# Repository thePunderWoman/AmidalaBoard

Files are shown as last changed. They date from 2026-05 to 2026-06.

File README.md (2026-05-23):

# AmidalaBoard (AmidalaShield)

A custom KiCad PCB shield designed specifically for the [Amidala Firmware](https://github.com/thePunderWoman/AmidalaFirmware) — a control system for astromech and similar droid builds. This board provides all the I/O the firmware needs in a single, purpose-built package.

**Designed by [thePunderWoman](https://github.com/thePunderWoman)**

---

## Overview

The AmidalaShield is a carrier/breakout board for the **ESP32-S3 N16R8 DevKit**. It breaks out and conditions the ESP32-S3's peripherals for the specific needs of the Amidala Firmware: wireless XBee communication, multi-channel servo control, RC receiver input, SD card storage, and expansion headers for additional peripherals.

---

## Requirements

- **Microcontroller:** ESP32-S3 N16R8 DevKit (16 MB flash, 8 MB PSRAM)
- **Wireless modules:** XBee3 modules (x2 recommended — one for drive controller, one for dome controller)

---

## Hardware Features

### Wireless Communication
- **2× XBee3 module sockets** for dual-controller operation (drive + dome)

### Servo Control
- **8× PWM servo outputs** — 3-pin headers (signal, power, ground)

### Serial Ports
- **2× hardware serial ports** — UART0 (shared with USB/programming) and UART1
- **1× software serial port** — for additional peripherals

### I/O
- **6× digital I/O pins**
- **2× analog input pins**
- **1× Aux I2C header** — for external I2C devices

### RC Control
- **PPM input (ppmin)** — for analog RC receiver
- **RC select (rcsel)** — RC source selection
- **sel2** — secondary selection/mode pin

### Storage
- **Built-in microSD card reader** — used for `config.txt` at startup (matches Amidala Firmware config system)

### Expansion
- **Dedicated SPI header** — for external SPI peripherals

---

## Repository Contents

| File/Folder | Description |
|---|---|
| `AmidalaShield.kicad_sch` | Top-level schematic |
| `comms.kicad_sch` | XBee communications sub-sheet |
| `io.kicad_sch` | Digital/analog I/O sub-sheet |
| `power.kicad_sch` | Power distribution sub-sheet |
| `rc_control.kicad_sch` | RC input sub-sheet |
| `servos.kicad_sch` | Servo output sub-sheet |
| `spi.kicad_sch` | SPI header sub-sheet |
| `gerbers/` | Production-ready Gerber files |
| `libraries/` | Project-specific KiCad symbol/footprint libraries |
| `images/` | Board renders and screenshots |

---

## Getting Started

1. Clone this repo and open `AmidalaShield.kicad_pro` in KiCad 8+.
2. Review the schematics for pin assignments before assembling.
3. Use the Gerber files in `gerbers/` to order PCBs from your preferred fab.
4. Flash your ESP32-S3 with the [Amidala Firmware](https://github.com/thePunderWoman/AmidalaFirmware).
5. Place a `config.txt` on the microSD card — see the firmware repo for a full annotated example.

---

## GPIO Table

> **V1.1** — Updated GPIO assignments for ESP32-S3 WROOM-1 N8R2/N16R2 (Quad flash/PSRAM).
> Avoid GPIO35–37 on R8 (Octal) variants. GPIO48 reserved for onboard RGB LED.

| Function | GPIO | DevKit Side | Notes |
|---|---|---|---|
| **SPI MOSI** | GPIO11 | Left | Native FSPI, shared bus |
| **SPI MISO** | GPIO13 | Left | Native FSPI, shared bus |
| **SPI SCK** | GPIO12 | Left | Native FSPI, shared bus |
| **SD Card CS** | GPIO10 | Left | |
| **XBee CS** | GPIO7 | Left | |
| **SPI Spare CS** | GPIO14 | Left | Exposed header |
| **XBee ATTN** | GPIO16 | Left | |
| **XBee SLEEP** | GPIO15 | Left | |
| **I2C SDA** | GPIO8 | Left | Native I2C default |
| **I2C SCL** | GPIO9 | Left | Native I2C default |
| **UART0 TX** | GPIO43 | Right | Shared w/ USB — do not use simultaneously |
| **UART0 RX** | GPIO44 | Right | Shared w/ USB — do not use simultaneously |
| **UART1 TX** | GPIO17 | Right | Primary droid brain serial |
| **UART1 RX** | GPIO18 | Right | |
| **SW-UART TX** | GPIO21 | Right | |
| **SW-UART RX** | GPIO38 | Right | |
| **PPMIN** | GPIO47 | Right | |
| **Analog 1** | GPIO1 | Right | ADC1_0, WiFi-safe |
| **Analog 2** | GPIO2 | Right | ADC1_1, WiFi-safe |
| **Servo 1** | GPIO3 | Left | Strapping pin (JTAG source), safe after boot |
| **Servo 2** | GPIO4 | Left | |
| **Servo 3** | GPIO5 | Left | |
| **Servo 4** | GPIO6 | Left | |
| **Digital 1** | GPIO39 | Right | Goes HIGH after reset (not LOW like most GPIOs) |
| **Digital 2** | GPIO40 | Right | |
| **Digital 3** | GPIO41 | Right | |
| **Digital 4** | GPIO42 | Right | Transitions low on reset slightly slower |
| **RGB LED** | GPIO48 | Right | Reserved — onboard DevKit RGB LED |
| **NC** | GPIO8 | Left | Reserved |

### Pins Intentionally Avoided

| GPIO | Reason |
|---|---|
| GPIO0 | Strapping pin — boot mode |
| GPIO3 | Strapping pin — JTAG source (used for Servo 1, safe after boot) |
| GPIO19/20 | USB D-/D+ |
| GPIO26–32 | Internal SPI flash/PSRAM — never use |
| GPIO35–37 | Internal on Octal (R8) variants — safe on R2 only |
| GPIO45 | Strapping pin — VDD_SPI voltage |
| GPIO46 | Strapping pin |

---

## License

This hardware design is licensed under the [Creative Commons Attribution-NonCommercial-ShareAlike 4.0 International License](LICENSE.md) (CC BY-NC-SA 4.0).

You are free to share and adapt this design for non-commercial purposes, as long as you give appropriate credit and distribute any adaptations under the same license.

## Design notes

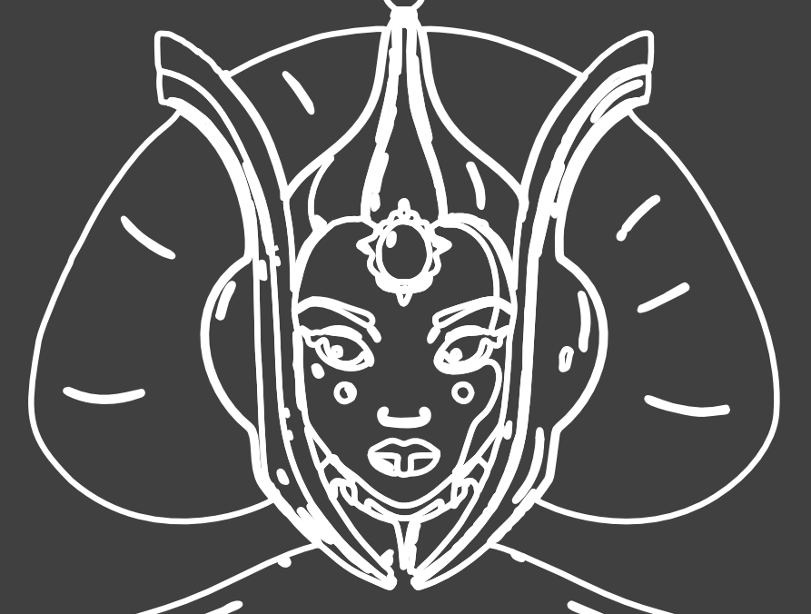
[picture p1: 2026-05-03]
images/amidala-screen.png

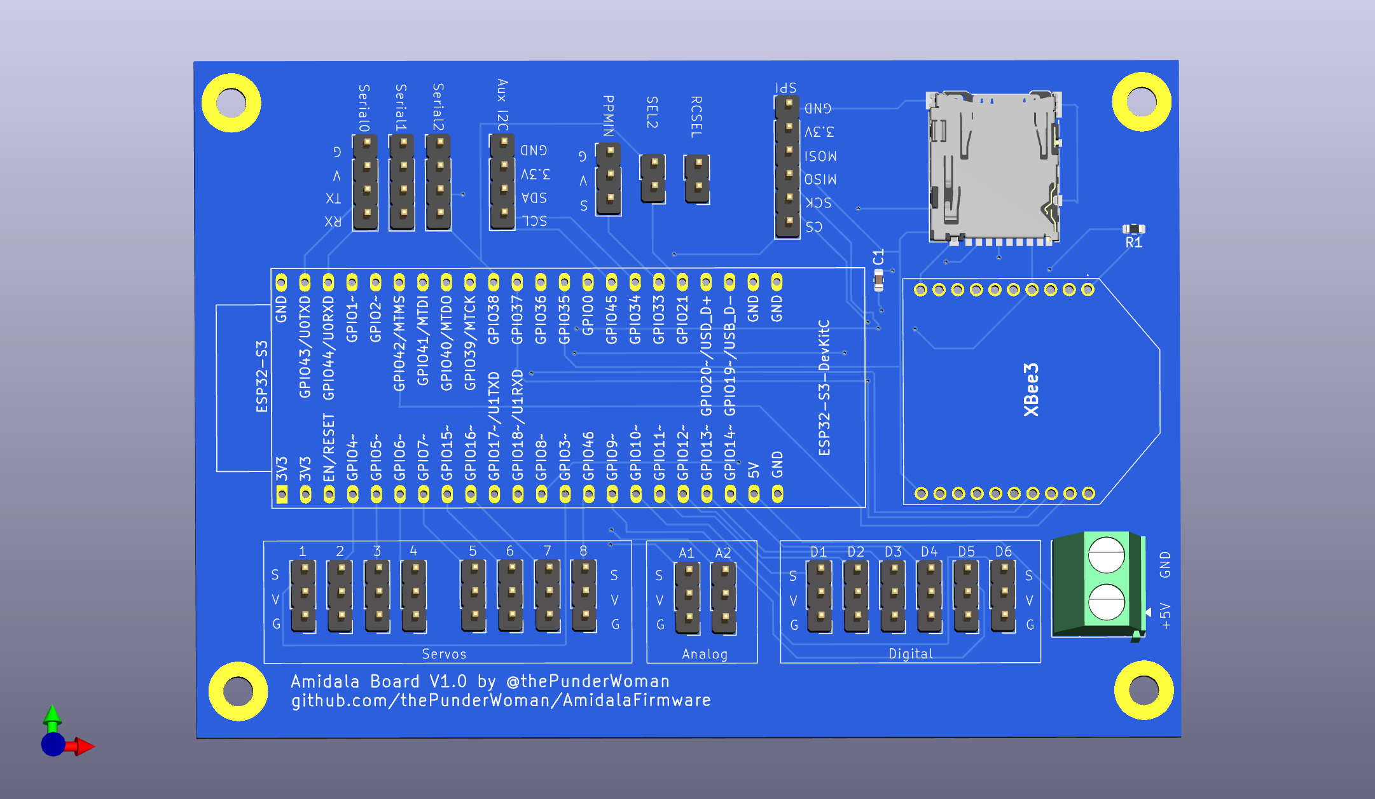
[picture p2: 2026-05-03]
V1-PCB.png

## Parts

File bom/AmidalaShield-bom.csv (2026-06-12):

Id | Designator | Footprint | Quantity | Designation | Supplier and ref
1 | C9 | CP_EIA-3216-18_Kemet-A | 1 | 100µF
2 | C4,C7 | C_0805_2012Metric | 2 | 10u
3 | C3,C2,C1 | C_0603_1608Metric | 3 | 100n
4 | R1,R5,R3,R2 | R_0603_1608Metric | 4 | 10k
5 | C6 | C_0603_1608Metric | 1 | 8.2p
6 | C5 | C_0603_1608Metric | 1 | 1u
7 | J3 | microSD_HC_Hirose_DM3AT-SF-PEJM5 | 1 | Micro_SD_Card

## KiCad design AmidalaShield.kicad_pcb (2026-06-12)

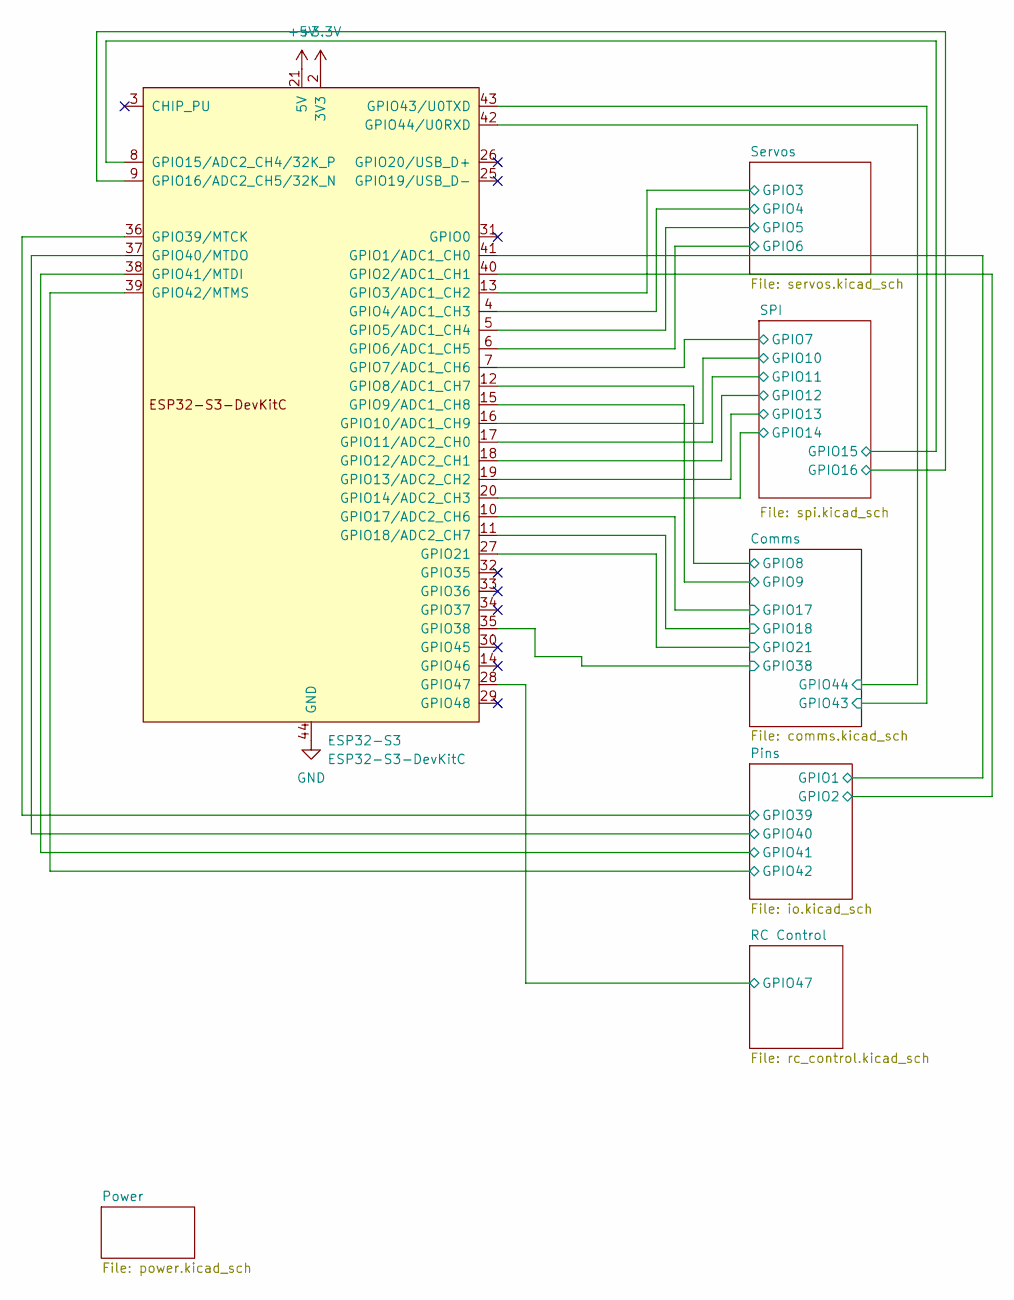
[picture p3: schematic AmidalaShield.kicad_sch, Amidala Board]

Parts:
ESP32-S3: ESP32-S3-DevKitC; ESP32-S2-DevKitC-1

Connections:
+3.3V: ESP32-S3.1 (3V3), ESP32-S3.2 (3V3); also elsewhere on the board
+5V: ESP32-S3.21 (5V); also elsewhere on the board
/Comms/GPIO8: ESP32-S3.12 (GPIO8/ADC1_CH7); also elsewhere on the board
/Comms/GPIO9: ESP32-S3.15 (GPIO9/ADC1_CH8); also elsewhere on the board
/Comms/GPIO17: ESP32-S3.10 (GPIO17/ADC2_CH6); also elsewhere on the board
/Comms/GPIO18: ESP32-S3.11 (GPIO18/ADC2_CH7); also elsewhere on the board
/Comms/GPIO21: ESP32-S3.27 (GPIO21); also elsewhere on the board
/Comms/GPIO38: ESP32-S3.35 (GPIO38); also elsewhere on the board
/Comms/GPIO43: ESP32-S3.43 (GPIO43/U0TXD); also elsewhere on the board
/Comms/GPIO44: ESP32-S3.42 (GPIO44/U0RXD); also elsewhere on the board
/Pins/GPIO1: ESP32-S3.41 (GPIO1/ADC1_CH0); also elsewhere on the board
/Pins/GPIO2: ESP32-S3.40 (GPIO2/ADC1_CH1); also elsewhere on the board
/Pins/GPIO39: ESP32-S3.36 (GPIO39/MTCK); also elsewhere on the board
/Pins/GPIO40: ESP32-S3.37 (GPIO40/MTDO); also elsewhere on the board
/Pins/GPIO41: ESP32-S3.38 (GPIO41/MTDI); also elsewhere on the board
/Pins/GPIO42: ESP32-S3.39 (GPIO42/MTMS); also elsewhere on the board
/RC Control/GPIO47: ESP32-S3.28 (GPIO47); also elsewhere on the board
/SPI/GPIO7: ESP32-S3.7 (GPIO7/ADC1_CH6); also elsewhere on the board
/SPI/GPIO10: ESP32-S3.16 (GPIO10/ADC1_CH9); also elsewhere on the board
/SPI/GPIO11: ESP32-S3.17 (GPIO11/ADC2_CH0); also elsewhere on the board
/SPI/GPIO12: ESP32-S3.18 (GPIO12/ADC2_CH1); also elsewhere on the board
/SPI/GPIO13: ESP32-S3.19 (GPIO13/ADC2_CH2); also elsewhere on the board
/SPI/GPIO14: ESP32-S3.20 (GPIO14/ADC2_CH3); also elsewhere on the board
/SPI/GPIO15: ESP32-S3.8 (GPIO15/ADC2_CH4/32K_P); also elsewhere on the board
/SPI/GPIO16: ESP32-S3.9 (GPIO16/ADC2_CH5/32K_N); also elsewhere on the board
/Servos/GPIO3: ESP32-S3.13 (GPIO3/ADC1_CH2); also elsewhere on the board
/Servos/GPIO4: ESP32-S3.4 (GPIO4/ADC1_CH3); also elsewhere on the board
/Servos/GPIO5: ESP32-S3.5 (GPIO5/ADC1_CH4); also elsewhere on the board
/Servos/GPIO6: ESP32-S3.6 (GPIO6/ADC1_CH5); also elsewhere on the board
GND: ESP32-S3.22 (GND), ESP32-S3.23 (GND), ESP32-S3.24 (GND), ESP32-S3.44 (GND); also elsewhere on the board

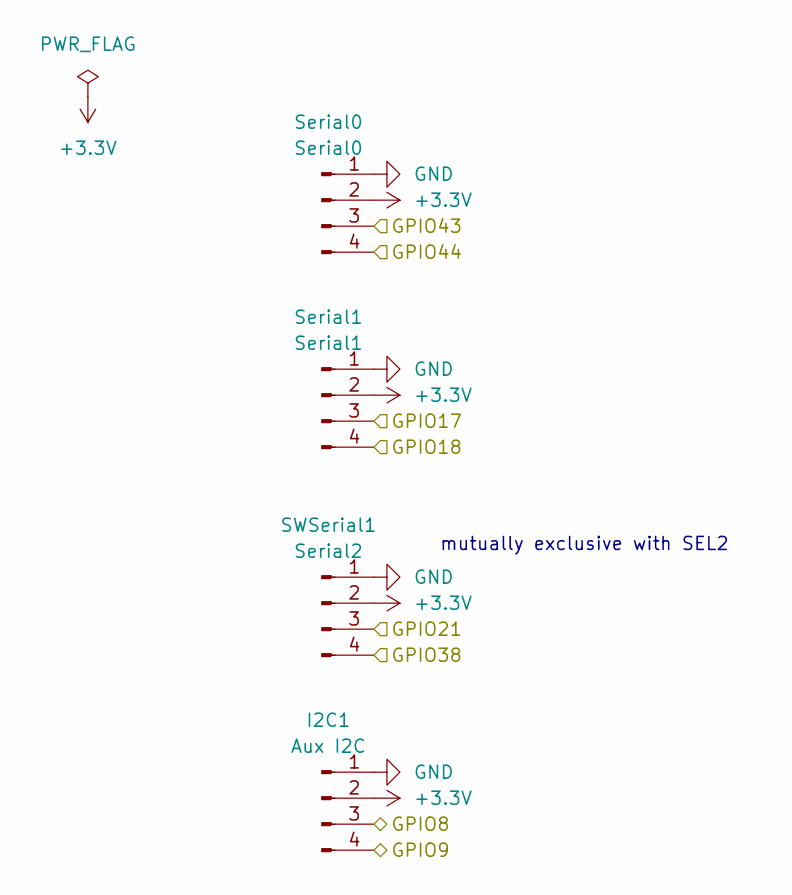
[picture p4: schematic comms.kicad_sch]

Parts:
I2C1: Aux I2C; PinHeader_1x04_P2.54mm_Vertical
SWSerial1: Serial2; PinHeader_1x04_P2.54mm_Vertical
Serial0: Serial0; PinHeader_1x04_P2.54mm_Vertical
Serial1: Serial1; PinHeader_1x04_P2.54mm_Vertical

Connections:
+3.3V: I2C1.2, SWSerial1.2, Serial0.2, Serial1.2; also elsewhere on the board
/Comms/GPIO8: I2C1.3; also elsewhere on the board
/Comms/GPIO9: I2C1.4; also elsewhere on the board
/Comms/GPIO17: Serial1.3; also elsewhere on the board
/Comms/GPIO18: Serial1.4; also elsewhere on the board
/Comms/GPIO21: SWSerial1.3; also elsewhere on the board
/Comms/GPIO38: SWSerial1.4; also elsewhere on the board
/Comms/GPIO43: Serial0.3; also elsewhere on the board
/Comms/GPIO44: Serial0.4; also elsewhere on the board
GND: I2C1.1, SWSerial1.1, Serial0.1, Serial1.1; also elsewhere on the board

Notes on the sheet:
mutually exclusive with SEL2

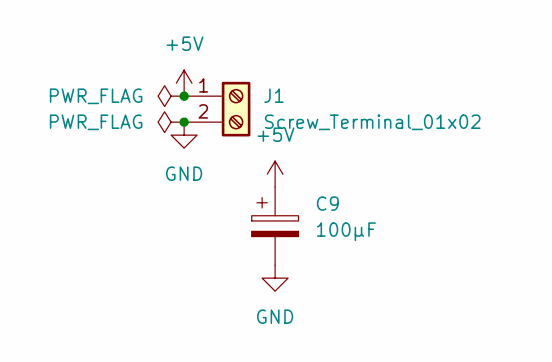
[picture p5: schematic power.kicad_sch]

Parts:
C9: 100µF; CP_EIA-3216-18_Kemet-A
J1: Screw_Terminal_01x02; TerminalBlock_Phoenix_MKDS-1,5-2-5.08_1x02_P5.08mm_Horizont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

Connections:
+5V: C9.1, J1.1; also elsewhere on the board
GND: C9.2, J1.2; also elsewhere on the board

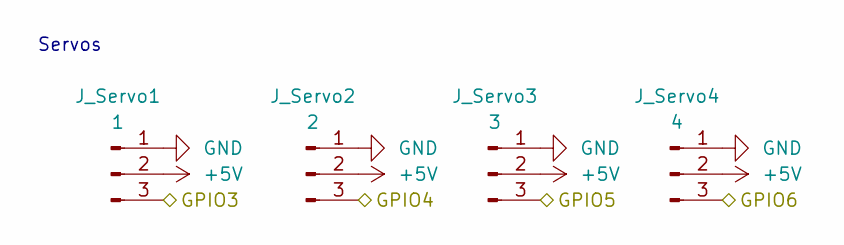
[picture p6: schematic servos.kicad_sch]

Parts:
J_Servo1: 1; PinHeader_1x03_P2.54mm_Vertical
J_Servo2: 2; PinHeader_1x03_P2.54mm_Vertical
J_Servo3: 3; PinHeader_1x03_P2.54mm_Vertical
J_Servo4: 4; PinHeader_1x03_P2.54mm_Vertical

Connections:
+5V: J_Servo1.2, J_Servo2.2, J_Servo3.2, J_Servo4.2; also elsewhere on the board
/Servos/GPIO3: J_Servo1.3; also elsewhere on the board
/Servos/GPIO4: J_Servo2.3; also elsewhere on the board
/Servos/GPIO5: J_Servo3.3; also elsewhere on the board
/Servos/GPIO6: J_Servo4.3; also elsewhere on the board
GND: J_Servo1.1, J_Servo2.1, J_Servo3.1, J_Servo4.1; also elsewhere on the board

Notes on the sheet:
Servos

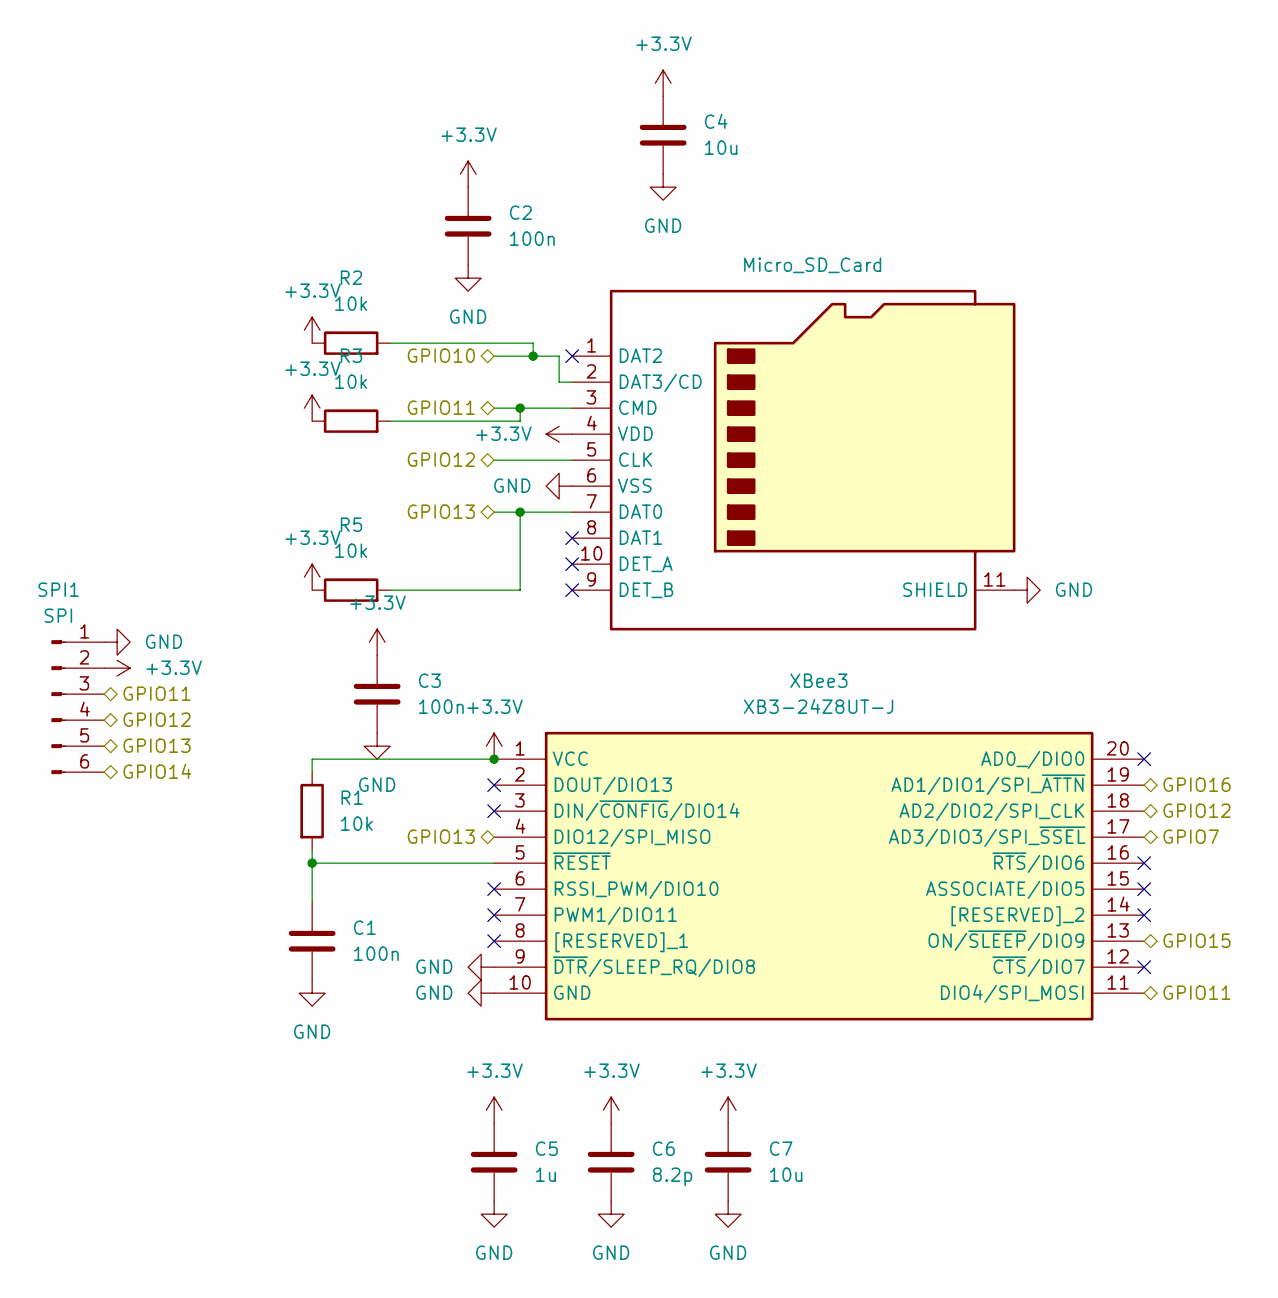
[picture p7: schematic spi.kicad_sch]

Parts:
C1, C2, C3: 100n; C_0603_1608Metric
C4, C7: 10u; C_0805_2012Metric
C5: 1u; C_0603_1608Metric
C6: 8.2p; C_0603_1608Metric
J3: Micro_SD_Card; microSD_HC_Hirose_DM3AT-SF-PEJM5
R1, R2, R3, R5: 10k; R_0603_1608Metric
SPI1: SPI; PinHeader_1x06_P2.54mm_Vertical
XBee3: XB3-24Z8UT-J; XB324Z8UTJ; Mouser Part Number 888-XB3-24Z8UT-J

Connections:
+3.3V: C2.1, C3.1, C4.1, C5.1, C6.1, C7.1, J3.4 (VDD), R1.1, R2.1, R3.1, R5.1, SPI1.2, XBee3.1 (VCC); also elsewhere on the board
/SPI/GPIO7: XBee3.17 (AD3/DIO3/SPI_~SSEL); also elsewhere on the board
/SPI/GPIO10: J3.2 (DAT3/CD), R2.2; also elsewhere on the board
/SPI/GPIO11: J3.3 (CMD), R3.2, SPI1.3, XBee3.11 (DIO4/SPI_MOSI); also elsewhere on the board
/SPI/GPIO12: J3.5 (CLK), SPI1.4, XBee3.18 (AD2/DIO2/SPI_CLK); also elsewhere on the board
/SPI/GPIO13: J3.7 (DAT0), R5.2, SPI1.5, XBee3.4 (DIO12/SPI_MISO); also elsewhere on the board
/SPI/GPIO14: SPI1.6; also elsewhere on the board
/SPI/GPIO15: XBee3.13 (ON/~SLEEP/DIO9); also elsewhere on the board
/SPI/GPIO16: XBee3.19 (AD1/DIO1/SPI_~ATTN); also elsewhere on the board
GND: C1.2, C2.2, C3.2, C4.2, C5.2, C6.2, C7.2, J3.6 (VSS), J3.11 (SHIELD), SPI1.1, XBee3.9 (~DTR/SLEEP_RQ/DIO8), XBee3.10 (GND); also elsewhere on the board
unnamed: C1.1, R1.2, XBee3.5 (~RESET)

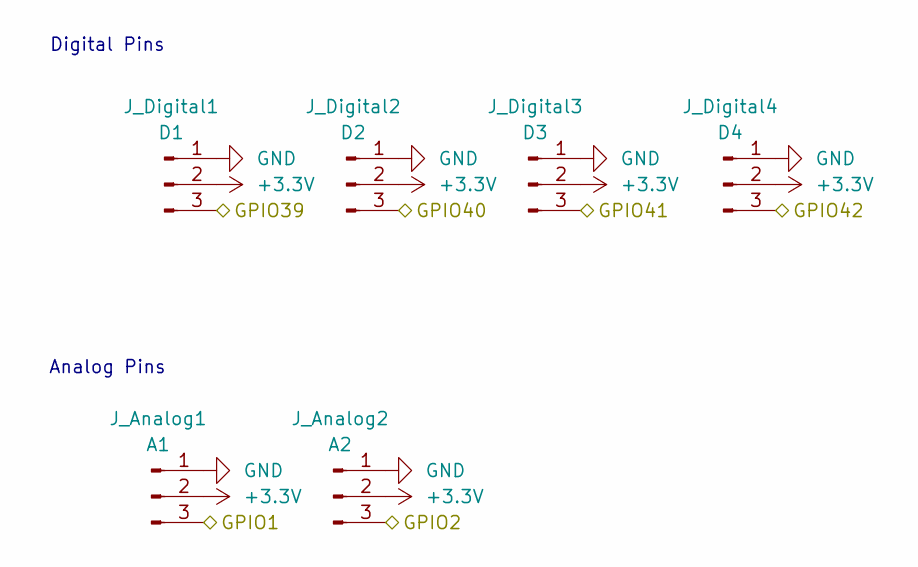
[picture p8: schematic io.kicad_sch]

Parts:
J_Analog1: A1; PinHeader_1x03_P2.54mm_Vertical
J_Analog2: A2; PinHeader_1x03_P2.54mm_Vertical
J_Digital1: D1; PinHeader_1x03_P2.54mm_Vertical
J_Digital2: D2; PinHeader_1x03_P2.54mm_Vertical
J_Digital3: D3; PinHeader_1x03_P2.54mm_Vertical
J_Digital4: D4; PinHeader_1x03_P2.54mm_Vertical

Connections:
+3.3V: J_Analog1.2, J_Analog2.2, J_Digital1.2, J_Digital2.2, J_Digital3.2, J_Digital4.2; also elsewhere on the board
/Pins/GPIO1: J_Analog1.3; also elsewhere on the board
/Pins/GPIO2: J_Analog2.3; also elsewhere on the board
/Pins/GPIO39: J_Digital1.3; also elsewhere on the board
/Pins/GPIO40: J_Digital2.3; also elsewhere on the board
/Pins/GPIO41: J_Digital3.3; also elsewhere on the board
/Pins/GPIO42: J_Digital4.3; also elsewhere on the board
GND: J_Analog1.1, J_Analog2.1, J_Digital1.1, J_Digital2.1, J_Digital3.1, J_Digital4.1; also elsewhere on the board

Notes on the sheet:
Analog Pins
Digital Pins

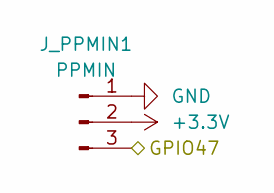
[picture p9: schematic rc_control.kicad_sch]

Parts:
J_PPMIN1: PPMIN; PinHeader_1x03_P2.54mm_Vertical

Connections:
+3.3V: J_PPMIN1.2; also elsewhere on the board
/RC Control/GPIO47: J_PPMIN1.3; also elsewhere on the board
GND: J_PPMIN1.1; also elsewhere on the board

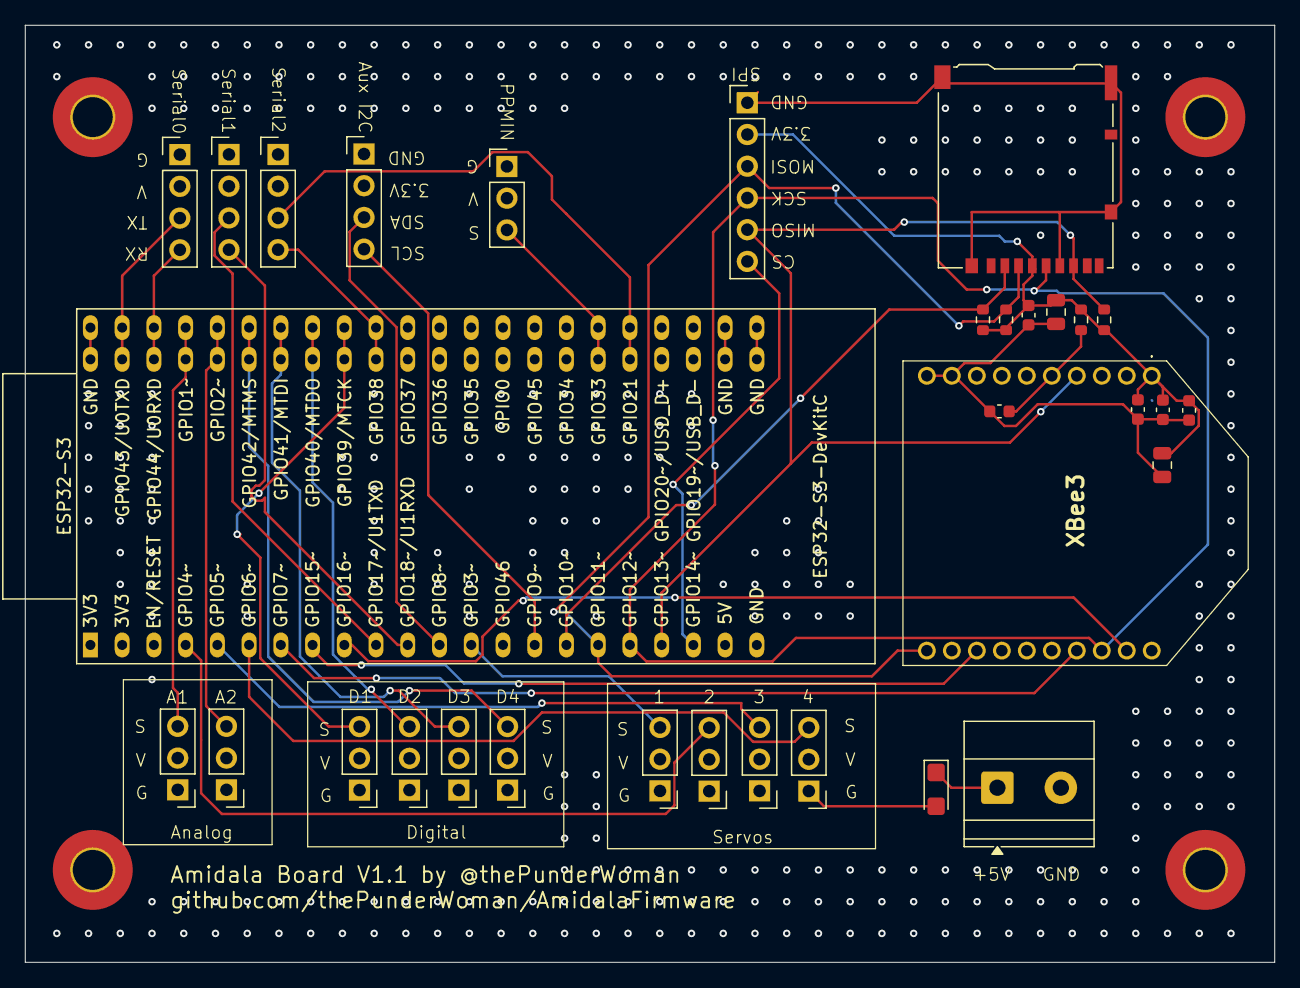
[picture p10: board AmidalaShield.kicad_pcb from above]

Board: 4 copper layers, 100.0 x 75.0 mm, 32 parts (0 on the bottom side), 31 nets.

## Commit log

2026-05-03 Switched SD Card slots
    [AmidalaShield-B_Courtyard.gbr, AmidalaShield-B_Cu.gbr, AmidalaShield-B_Mask.gbr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]
2026-05-03 Remapped GPIOs for clean routing
    This updates the GPIO table so that the traces and vias are far cleaner. Slight repositioning of some pins to account for that. Rebuilt all gerbers and necessary stuff.
    [AmidalaShield-B_Courtyard.gbr, AmidalaShield-B_Cu.gbr, AmidalaShield-B_Mask.gbr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]
2026-05-03 final pass safety check
    This verified that the XBee had all the pins wired up correctly with the proper resistor and cap connections. Glad I caught this before getting them fabbed.
    [AmidalaShield-B_Courtyard.gbr, AmidalaShield-B_Cu.gbr, AmidalaShield-B_Mask.gbr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]
2026-05-23 Updated to v1.1 to fix issues
    [AmidalaShield-B_Courtyard.gbr, AmidalaShield-B_Cu.gbr, AmidalaShield-B_Mask.gbr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]
2026-06-12 Updated to v1.2 to address remaining issues
    [AmidalaShield-B_Cu.gbl, AmidalaShield-B_Mask.gbr, AmidalaShield-B_Mask.gbs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]
